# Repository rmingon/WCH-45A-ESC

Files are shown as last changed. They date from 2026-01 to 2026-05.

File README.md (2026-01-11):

# WCH-45A-ESC

An open-hardware 45A Electronic Speed Controller (ESC) project based on the WCH CH32M007 RISC-V microcontroller.

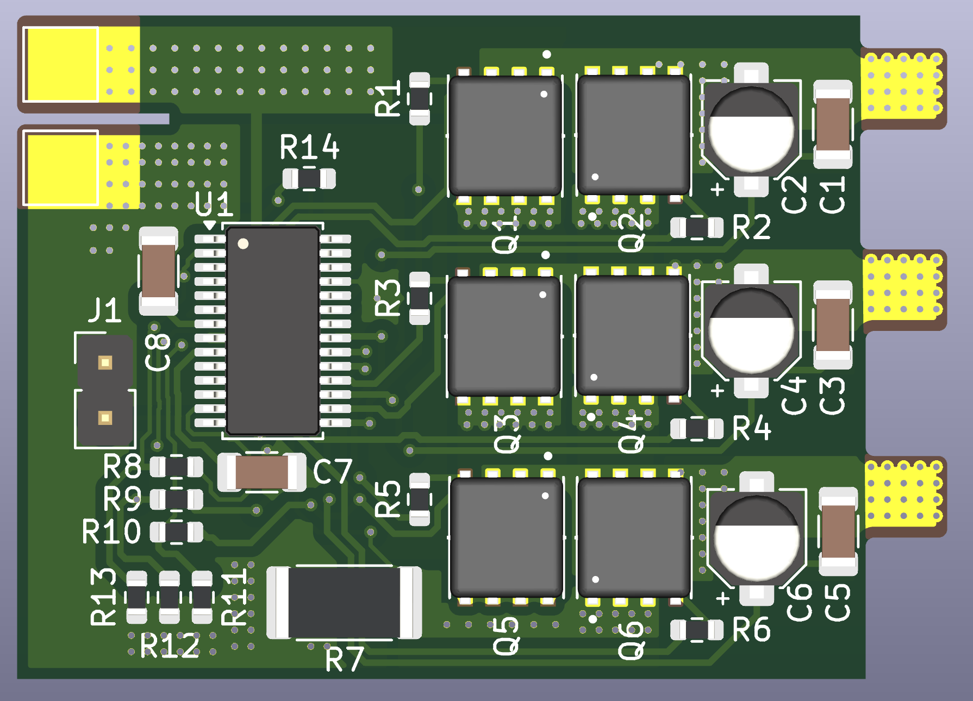
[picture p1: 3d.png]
3d

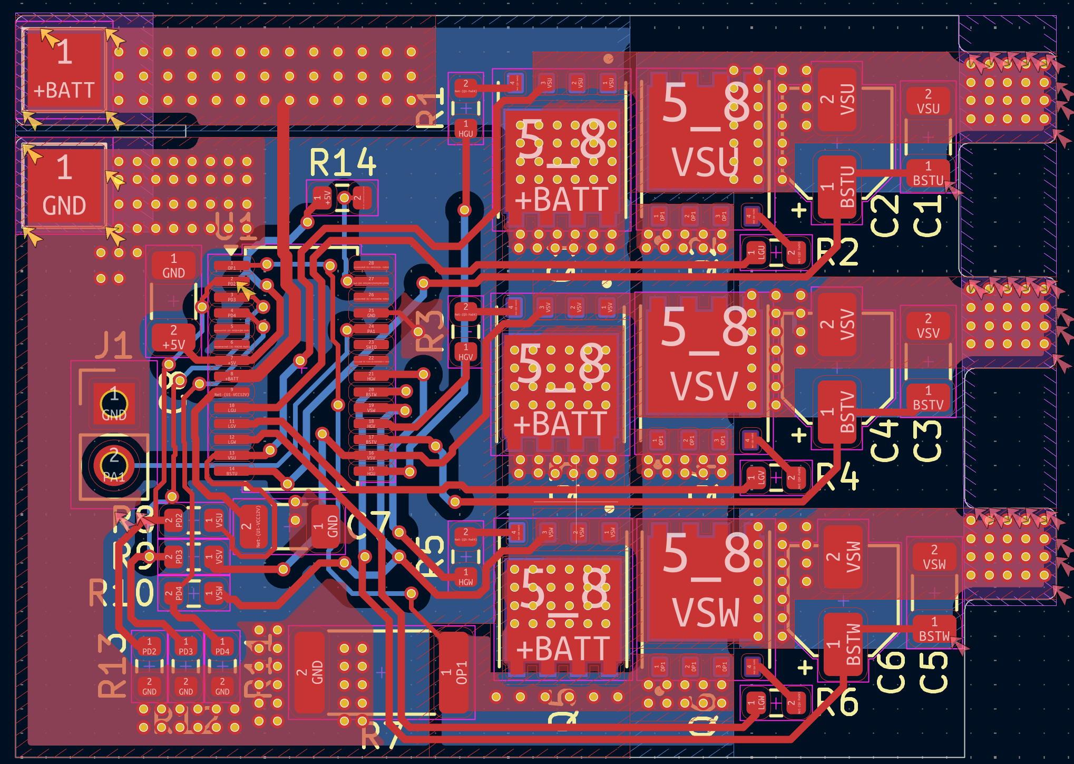
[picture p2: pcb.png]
PCB

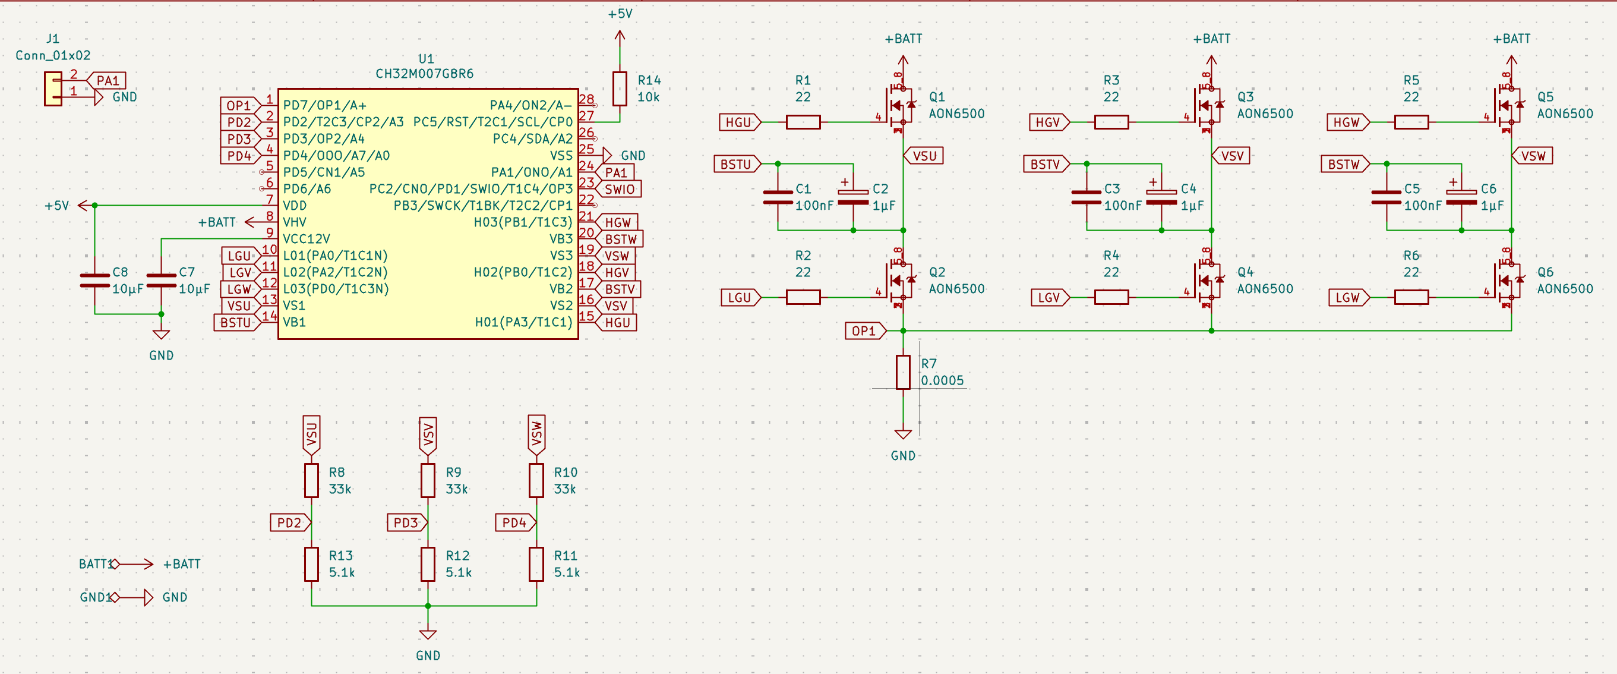
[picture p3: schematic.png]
Schematic


## Project Overview

This project aims to provide a robust and cost-effective ESC capable of handling continuous currents up to 45A. It utilizes the CH32M007G8R6, a RISC-V MCU specifically designed for motor control applications with integrated op-amps and comparators.

### Why Choose the CH32M007?

The **WCH CH32M007** stands out as a premier choice for modern **motor control applications**. Key advantages include:

- **Integrated Analog Peripherals:** With **3x built-in Op-Amps** and **4x Comparators**, the CH32M007 simplifies **current sensing** and **BEMF detection** layouts, reducing external component count and **BOM cost**.
- **High-Performance RISC-V Core:** The **144MHz QingKe V4F core** delivers the computational speed required for complex **FOC (Field Oriented Control)** loops and high-RPM management.
- **Dedicated Motor Control Logic:** Features advanced timers for complementary PWM generation with hardware dead-time, ensuring safe and efficient **MOSFET switching**.
- **Cost Efficiency:** It offers a highly competitive price point for **BLDC** and **PMSM** driver solutions without compromising on performance.

## Hardware Design

### MOSFET Selection

The power stage is the most critical aspect of this 45A design. We selected the **Alpha & Omega AON6500** N-Channel MOSFET for the following reasons:

1.  **Ultra-Low On-Resistance ($R_{DS(on)}$):** With a typical resistance of **~1.0 mΩ** (at $V_{GS}=10V$), conduction losses ($P = I^2 R$) are drastically reduced. This allows the ESC to handle 45A continuous current with minimal heat generation.
2.  **Thermal Management:** The **DFN5x6** package provides excellent thermal coupling to the PCB copper pours, eliminating the need for bulky external heatsinks in typical airflow conditions.
3.  **Voltage Rating ($V_{DS}$):** The **30V** breakdown voltage offers sufficient headroom for 2S-4S LiPo configurations, capable of withstanding inductive voltage spikes during switching.
4.  **Optimized Gate Charge:** The gate charge is balanced to allow for fast switching speeds (reducing switching losses) while remaining within the drive capability of the gate driver circuitry.

### CH32M007 KiCad Symbol

The custom KiCad schematic symbol and footprint for the **CH32M007G8R6** are included directly in this repository.

- **Location:** See the `root` repo.
- **Usage:** These libraries can be imported into KiCad to modify the design or create new derivatives.

## Firmware & Programming

The firmware source code is located in the `software` folder. The project is specifically configured for **MounRiver Studio 2**.

### How to Program

To flash the firmware onto the CH32M007, you will need a **WCH-LinkE** or compatible programmer.

1.  **Connections:**
    - Connect the **SWDIO**, **SWCLK**, **3V3**, and **GND** pads on the ESC to the WCH-Link.
2.  **Toolchain:**

    - The project is set up to use the `RISC-V Cross GCC` toolchain.
    - Build the project to generate the `.hex` or `.elf` file.

3.  **Flashing:**
    - Use **WCH-LinkUtility** or the built-in flasher in MounRiver Studio.
    - Select the CH32M007 series chip and download the firmware.

## License

This project is licensed under the **CERN Open Hardware Licence Version 2 - Strongly Reciprocal (CERN-OHL-S)**.

```text
CERN Open Hardware Licence Version 2 (Strongly Reciprocal) — CERN-OHL-S v2.0

You may obtain a copy of the license text from CERN:
https://ohwr.org/project/cernohl/wikis/Documents/CERN-OHL-version-2
```

If you redistribute this project (in source or manufactured form), you must comply with the terms of CERN-OHL-S v2.0.

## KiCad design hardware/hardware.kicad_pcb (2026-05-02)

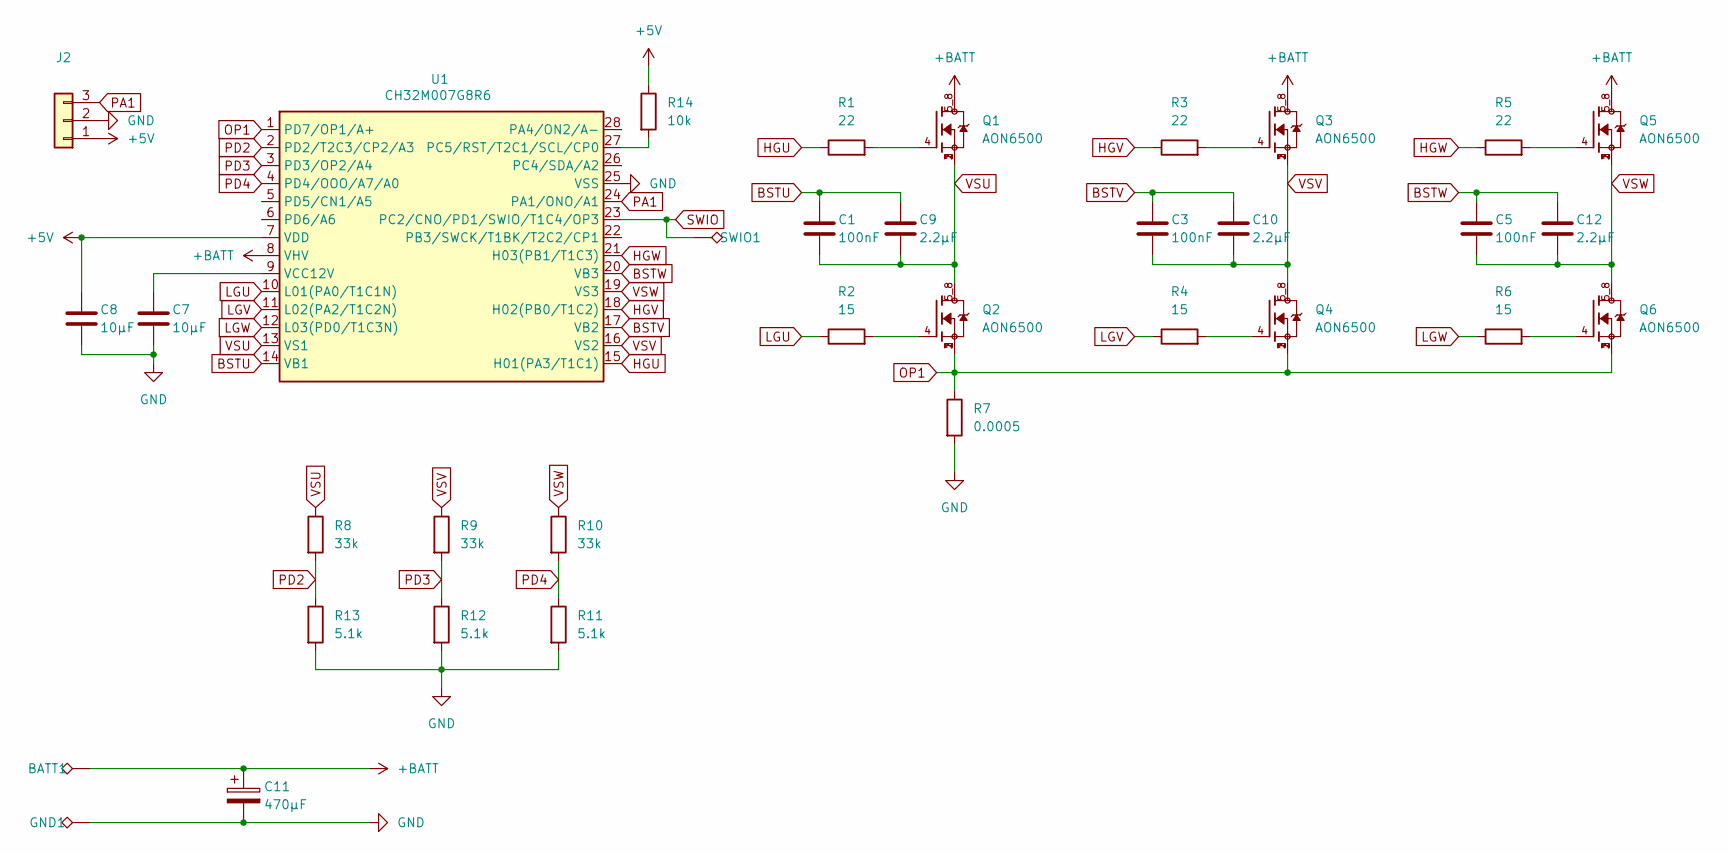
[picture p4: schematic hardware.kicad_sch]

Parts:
BATT1: TestPoint_Alt; TestPoint_Pad_3.0x3.0mm
C1, C3, C5: 100nF; C_1206_3216Metric
C7, C8: 10µF; C_1206_3216Metric
C9, C10, C12: 2.2µF; C_1206_3216Metric
C11: 470µF; CP_Radial_D10.0mm_P5.00mm
GND1: TestPoint_Alt; TestPoint_Pad_3.0x3.0mm
J2: Conn_01x03; PinHeader_1x03_P2.54mm_Vertical
Q1, Q2, Q3, Q4, Q5, Q6: AON6500; TRANS_AON6500; PARTREV F
R1, R3, R5: 22; R_0603_1608Metric
R2, R4, R6: 15; R_0603_1608Metric
R7: 0.0005; R_2512_6332Metric
R8, R9, R10: 33k; R_0603_1608Metric
R11, R12, R13: 5.1k; R_0603_1608Metric
R14: 10k; R_0603_1608Metric
SWIO1: TestPoint_Alt; TestPoint_Pad_1.5x1.5mm
U1: CH32M007G8R6; TSSOP-28_4.4x9.7mm_P0.65mm

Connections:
+5V: C8.2, J2.1, R14.1, U1.7 (VDD)
+BATT: BATT1.1 (1_1), C11.1, Q1.5_8, Q3.5_8, Q5.5_8, U1.8 (VHV)
BSTU: C1.1, C9.2, U1.14 (VB1)
BSTV: C3.1, C10.2, U1.17 (VB2)
BSTW: C5.1, C12.2, U1.20 (VB3)
GND: C7.1, C8.1, C11.2, GND1.1 (1_1), J2.2, R7.2, R11.2, R12.2, R13.2, U1.25 (VSS)
HGU: R1.1, U1.15 (H01(PA3/T1C1))
HGV: R3.1, U1.18 (H02(PB0/T1C2))
HGW: R5.1, U1.21 (H03(PB1/T1C3))
LGU: R2.1, U1.10 (L01(PA0/T1C1N))
LGV: R4.1, U1.11 (L02(PA2/T1C2N))
LGW: R6.1, U1.12 (L03(PD0/T1C3N))
unnamed: Q1.4, R1.2
unnamed: Q2.4, R2.2
unnamed: Q3.4, R3.2
unnamed: Q4.4, R4.2
unnamed: Q5.4, R5.2
unnamed: Q6.4, R6.2
unnamed: R14.2, U1.27 (PC5/RST/T2C1/SCL/CP0)
unnamed: C7.2, U1.9 (VCC12V)
OP1: Q2.1, Q2.2, Q2.3, Q4.1, Q4.2, Q4.3, Q6.1, Q6.2, Q6.3, R7.1, U1.1 (PD7/OP1/A+)
PA1: J2.3, U1.24 (PA1/ONO/A1)
PD2: R8.2, R13.1, U1.2 (PD2/T2C3/CP2/A3)
PD3: R9.2, R12.1, U1.3 (PD3/OP2/A4)
PD4: R10.2, R11.1, U1.4 (PD4/OOO/A7/A0)
SWIO: SWIO1.1 (1_1), U1.23 (PC2/CNO/PD1/SWIO/T1C4/OP3)
VSU: C1.2, C9.1, Q1.1, Q1.2, Q1.3, Q2.5_8, R8.1, U1.13 (VS1)
VSV: C3.2, C10.1, Q3.1, Q3.2, Q3.3, Q4.5_8, R9.1, U1.16 (VS2)
VSW: C5.2, C12.1, Q5.1, Q5.2, Q5.3, Q6.5_8, R10.1, U1.19 (VS3)

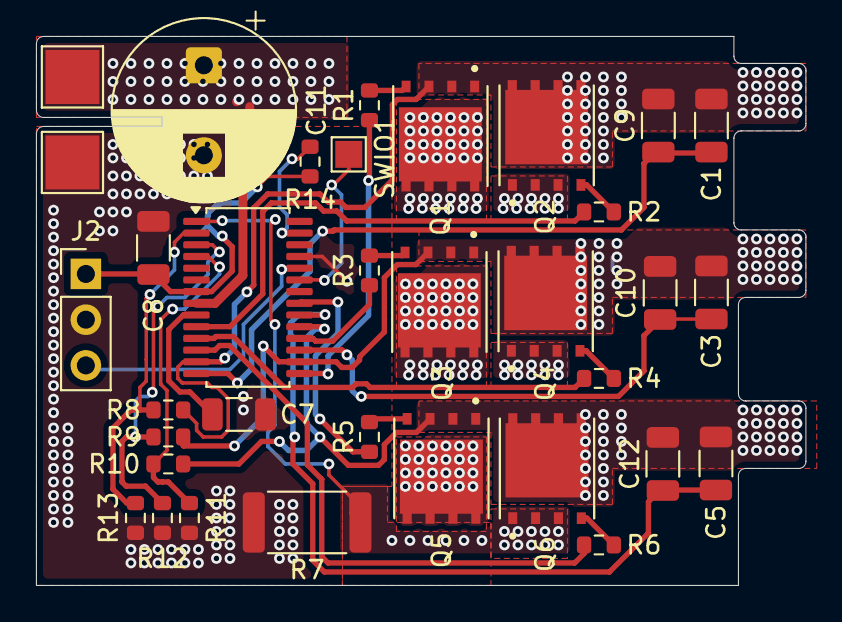
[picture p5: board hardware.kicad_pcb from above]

Board: 2 copper layers, 42.8 x 30.5 mm, 34 parts (0 on the bottom side), 29 nets.

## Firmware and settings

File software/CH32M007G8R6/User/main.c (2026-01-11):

#include "debug.h"

/* Global Variable to store Throttle */
volatile uint16_t PWM_PulseWidth = 0; // Throttle value (approx 1000 to 2000)
volatile uint16_t PWM_Period = 0;     // Frequency check

void TIM2_PWM_Input_Init(void)
{
    TIM_ICInitTypeDef TIM_ICInitStructure = {0};
    GPIO_InitTypeDef GPIO_InitStructure = {0};
    NVIC_InitTypeDef NVIC_InitStructure = {0};

    // 1. Enable Clocks
    // TIM2 is on APB1, GPIOA and AFIO on APB2
    RCC_PB1PeriphClockCmd(RCC_PB1Periph_TIM2, ENABLE);
    RCC_PB2PeriphClockCmd(RCC_PB2Periph_GPIOA | RCC_PB2Periph_AFIO, ENABLE);

    // 2. Configure PA1 as Input
    // We use Pull-Down to ensure throttle is "0" if wire disconnects
    // (User Note: You have an external 10k Pull-Up R14, consider removing it for safety)
    GPIO_InitStructure.GPIO_Pin = GPIO_Pin_1;
    GPIO_InitStructure.GPIO_Mode = GPIO_Mode_IPD; 
    GPIO_Init(GPIOA, &GPIO_InitStructure);

    // 3. Pin Remap (CRITICAL)
    // By default, PA1 is TIM1. We must remap to get TIM2_CH2 on PA1.
    // Check your ch32v00x_gpio.h for the exact definition. 
    // It is often GPIO_PartialRemap1_TIM2 or similar.
    // Uncomment the line below if PA1 is not default TIM2 for your specific package:
    // GPIO_PinRemapConfig(GPIO_FullRemap_TIM2, ENABLE); 

    // 4. Timer Base Config
    // Prescaler = 47 -> 48MHz / (47+1) = 1MHz Timer Clock
    // This gives us 1 microsecond (us) precision.
    TIM2->PSC = 47; 
    TIM2->ATRLR = 0xFFFF; // Max period

    // 5. PWM Input Configuration
    // We use Channel 2 (PA1) as the main input
    TIM_ICInitStructure.TIM_Channel = TIM_Channel_2;
    TIM_ICInitStructure.TIM_ICPolarity = TIM_ICPolarity_Rising; // Reset on Rising Edge
    TIM_ICInitStructure.TIM_ICSelection = TIM_ICSelection_DirectTI;
    TIM_ICInitStructure.TIM_ICPrescaler = TIM_ICPSC_DIV1;
    TIM_ICInitStructure.TIM_ICFilter = 0x0; // Add filter (e.g., 0x4) if you have noise
    
    // This function automatically configures Channel 1 to capture the Falling Edge
    TIM_PWMIConfig(TIM2, &TIM_ICInitStructure);

    // 6. Select Input Trigger: TI2FP2 (Channel 2 Filtered)
    TIM_SelectInputTrigger(TIM2, TIM_TS_TI2FP2);

    // 7. Slave Mode: Reset Counter on Rising Edge
    TIM_SelectSlaveMode(TIM2, TIM_SlaveMode_Reset);

    // 8. Enable Master/Slave Mode
    TIM_SelectMasterSlaveMode(TIM2, TIM_MasterSlaveMode_Enable);

    // 9. Enable Interrupts (Optional, if you want to read data in IRQ)
    TIM_ITConfig(TIM2, TIM_IT_CC2, ENABLE);

    NVIC_InitStructure.NVIC_IRQChannel = TIM2_IRQn;
    NVIC_InitStructure.NVIC_IRQChannelPreemptionPriority = 1;
    NVIC_InitStructure.NVIC_IRQChannelSubPriority = 1;
    NVIC_InitStructure.NVIC_IRQChannelCmd = ENABLE;
    NVIC_Init(&NVIC_InitStructure);

    // 10. Enable Timer
    TIM_Cmd(TIM2, ENABLE);
}

// Interrupt Handler to Read Data
void TIM2_IRQHandler(void) __attribute__((interrupt("WCH-Interrupt-fast")));
void TIM2_IRQHandler(void)
{
    if (TIM_GetITStatus(TIM2, TIM_IT_CC2) != RESET)
    {
        // CCR1 contains the Pulse Width (Falling edge capture)
        // CCR2 contains the Period (Next Rising edge capture)
        PWM_PulseWidth = TIM_GetCapture1(TIM2); 
        PWM_Period = TIM_GetCapture2(TIM2);
        
        TIM_ClearITPendingBit(TIM2, TIM_IT_CC2);
    }
}

int main(void)
{
    SystemInit();
    USART_Printf_Init(115200); // Initialize debug UART if needed
    
    TIM2_PWM_Input_Init();

    while(1)
    {
        // Safety: If PulseWidth is roughly 1000 to 2000, it's valid.
        // If it is 0, signal is lost.
        
        printf("Throttle: %d us\n", PWM_PulseWidth);
        
        // Delay 100ms
        for(volatile int i=0; i<100000; i++); 
    }
}

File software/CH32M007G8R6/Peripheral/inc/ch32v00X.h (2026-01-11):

/********************************** (C) COPYRIGHT  *******************************
 * File Name          : ch32v00X.h
 * Author             : WCH
 * Version            : V1.0.2
 * Date               : 2025/03/10
 * Description        : CH32V00X Device Peripheral Access Layer Header File.
 *********************************************************************************
 * Copyright (c) 2021 Nanjing Qinheng Microelectronics Co., Ltd.
 * Attention: This software (modified or not) and binary are used for 
 * microcontroller manufactured by Nanjing Qinheng Microelectronics.
 *******************************************************************************/
#ifndef __CH32V00X_H
#define __CH32V00X_H

#ifdef __cplusplus
extern "C" {
#endif

#if !defined(CH32V002) && !defined(CH32V004) && !defined(CH32V005) && !defined(CH32V006)&& !defined(CH32V007_M007)
//#define CH32V002             /* CH32V002*/
//#define CH32V004             /* CH32V004 */
//#define CH32V005             /* CH32V005 */
//#define CH32V006             /* CH32V006 */
#define CH32V007_M007        /* CH32V007 - CH32M007*/
#endif

#define __MPU_PRESENT             0 /* Other CH32 devices does not provide an MPU */
#define __Vendor_SysTickConfig    0 /* Set to 1 if different SysTick Config is used */

#ifndef HSE_VALUE
#define HSE_VALUE                 ((uint32_t)24000000) /* Value of the External oscillator in Hz */
#endif

/* In the following line adjust the External High Speed oscillator (HSE) Startup Timeout value */
#define HSE_STARTUP_TIMEOUT       ((uint16_t)0x2000) /* Time out for HSE start up */

#define HSI_VALUE                 ((uint32_t)24000000) /* Value of the Internal oscillator in Hz */

/* CH32V00X Standard Peripheral Library version number */
#define __CH32V00X_STDPERIPH_VERSION_MAIN   (0x01) /* [15:8] main version */
#define __CH32V00X_STDPERIPH_VERSION_SUB    (0x04) /* [7:0] sub version */
#define __CH32V00X_STDPERIPH_VERSION        ( (__CH32V00X_STDPERIPH_VERSION_MAIN << 8)\
                                             |(__CH32V00X_STDPERIPH_VERSION_SUB << 0))

/* Interrupt Number Definition, according to the selected device */
typedef enum IRQn
{
    /******  RISC-V Processor Exceptions Numbers *******************************************************/
    NonMaskableInt_IRQn = 2, /* 2 Non Maskable Interrupt                             */
    HardFault_IRQn = 3,      /* 3 HardFault Interrupt                                */
    SysTick_IRQn = 12,       /* 12 System timer Interrupt                            */
    Software_IRQn = 14,      /* 14 software Interrupt                                */

    /******  RISC-V specific Interrupt Numbers *********************************************************/
    WWDG_IRQn = 16,          /* Window WatchDog Interrupt                            */
    PVD_IRQn = 17,           /* PVD through EXTI Line detection Interrupt            */
    FLASH_IRQn = 18,         /* FLASH global Interrupt                               */
    RCC_IRQn = 19,           /* RCC global Interrupt                                 */
    EXTI7_0_IRQn = 20,       /* External Line[7:0] Interrupts                        */
    AWU_IRQn = 21,           /* AWU global Interrupt                                 */
    DMA1_Channel1_IRQn = 22, /* DMA1 Channel 1 global Interrupt                      */
    DMA1_Channel2_IRQn = 23, /* DMA1 Channel 2 global Interrupt                      */
    DMA1_Channel3_IRQn = 24, /* DMA1 Channel 3 global Interrupt                      */
    DMA1_Channel4_IRQn = 25, /* DMA1 Channel 4 global Interrupt                      */
    DMA1_Channel5_IRQn = 26, /* DMA1 Channel 5 global Interrupt                      */
    DMA1_Channel6_IRQn = 27, /* DMA1 Channel 6 global Interrupt                      */
    DMA1_Channel7_IRQn = 28, /* DMA1 Channel 7 global Interrupt                      */
    ADC_IRQn = 29,           /* ADC global Interrupt                                 */
    I2C1_EV_IRQn = 30,       /* I2C1 Event Interrupt                                 */
    I2C1_ER_IRQn = 31,       /* I2C1 Error Interrupt                                 */
    USART1_IRQn = 32,        /* USART1 global Interrupt                              */
    SPI1_IRQn = 33,          /* SPI1 global Interrupt                                */
    TIM1_BRK_IRQn = 34,      /* TIM1 Break Interrupt                                 */
    TIM1_UP_IRQn = 35,       /* TIM1 Update Interrupt                                */
    TIM1_TRG_COM_IRQn = 36,  /* TIM1 Trigger and Commutation Interrupt               */
    TIM1_CC_IRQn = 37,       /* TIM1 Capture Compare Interrupt                       */
    TIM2_IRQn = 38,          /* TIM2 global Interrupt                                */

#if defined(CH32V005) || defined(CH32V006) || defined(CH32V007_M007)
    USART2_IRQn = 39,        /* USART2 global Interrupt                              */
    OPCM_IRQn = 40,          /* OPCM global Interrupt                                */
#endif
} IRQn_Type;

#define SysTicK_IRQn      SysTick_IRQn

#include <stdint.h>
#include <core_riscv.h>
#include <system_ch32v00X.h>

/* Standard Peripheral Library old definitions (maintained for legacy purpose) */
#define HSI_Value             HSI_VALUE
#define HSE_Value             HSE_VALUE
#define HSEStartUp_TimeOut    HSE_STARTUP_TIMEOUT

/* Analog to Digital Converter */
typedef struct
{
    __IO uint32_t STATR;
    __IO uint32_t CTLR1;
    __IO uint32_t CTLR2;
    uint32_t RESERVED;
    __IO uint32_t SAMPTR2;
    __IO uint32_t IOFR1;
    __IO uint32_t IOFR2;
    __IO uint32_t IOFR3;
    __IO uint32_t IOFR4;
    __IO uint32_t WDHTR;
    __IO uint32_t WDLTR;
    __IO uint32_t RSQR1;
    __IO uint32_t RSQR2;
    __IO uint32_t RSQR3;
    __IO uint32_t ISQR;
    __IO uint32_t IDATAR1;
    __IO uint32_t IDATAR2;
    __IO uint32_t IDATAR3;
    __IO uint32_t IDATAR4;
    __IO uint32_t RDATAR;
    __IO uint32_t CTLR3;
    __IO uint32_t WDTR1;
    __IO uint32_t WDTR2;
} ADC_TypeDef;

/* DMA Controller */
typedef struct
{
    __IO uint32_t CFGR;
    __IO uint32_t CNTR;
    __IO uint32_t PADDR;
    __IO uint32_t MADDR;
} DMA_Channel_TypeDef;

typedef struct
{
    __IO uint32_t INTFR;
    __IO uint32_t INTFCR;
} DMA_TypeDef;

/* External Interrupt/Event Controller */
typedef struct
{
    __IO uint32_t INTENR;
    __IO uint32_t EVENR;
    __IO uint32_t RTENR;
    __IO uint32_t FTENR;
    __IO uint32_t SWIEVR;
    __IO uint32_t INTFR;
} EXTI_TypeDef;

/* FLASH Registers */
typedef struct
{
    __IO uint32_t ACTLR;
    __IO uint32_t KEYR;
    __IO uint32_t OBKEYR;
    __IO uint32_t STATR;
    __IO uint32_t CTLR;
    __IO uint32_t ADDR;
    uint32_t RESERVED;
    __IO uint32_t OBR;
    __IO uint32_t WPR;
    __IO uint32_t MODEKEYR;
    __IO uint32_t BOOT_MODEKEYR;
} FLASH_TypeDef;
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

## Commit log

2026-01-10 add mosfet wiring
    [hardware.kicad_pcb, hardware.kicad_sch]
2026-01-11 add ch32m007 kicad symbol
2026-01-11 wire esc + add minimal connector for ch32m007
    [hardware.kicad_pcb, hardware.kicad_sch]
2026-01-11 wire bemf
    [hardware.kicad_sch]
2026-01-11 add pad gnd and wire drivers with pwm
    [hardware.kicad_pcb, hardware.kicad_sch]
2026-01-11 finish wire pcb
    [hardware.kicad_pcb, hardware.kicad_sch]
2026-01-11 add programming pad
    [hardware.kicad_pcb, hardware.kicad_sch]
2026-01-11 add 3.3v connection
    [hardware.kicad_pcb, hardware.kicad_sch]
2026-05-02 add battery capacitor
    [hardware.kicad_pcb, hardware.kicad_sch]
2026-05-02 update capacitor
    [hardware.kicad_pcb, hardware.kicad_sch]
2026-05-02 change gate resistors
    [hardware.kicad_pcb, hardware.kicad_sch]
